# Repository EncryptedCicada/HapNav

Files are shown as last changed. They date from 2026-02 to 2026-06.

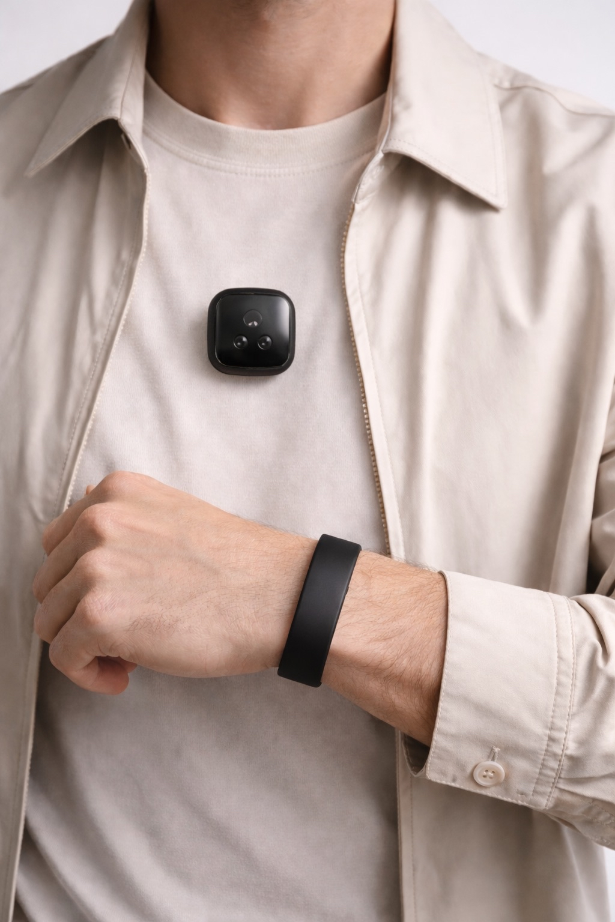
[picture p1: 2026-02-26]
Docs/Figures/Assets/HapNav_Components_Showcase-Mockup.png

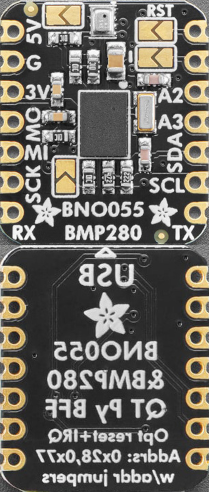
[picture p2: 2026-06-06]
Visualizer/assets/bno055+bmp280-atlas.png

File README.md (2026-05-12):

# HapNav — Haptic Navigation System for the Visually Impaired

⚠️ **This is NOT a pure software project.** HapNav requires physical hardware to build and run. You cannot simulate the full system in software alone. See the [Hardware Requirements](#hardware-requirements) section before cloning.

---

## Table of Contents

- [Overview](#overview)  
- [System Architecture](#system-architecture)  
- [Repository Structure](#repository-structure)  
- [Hardware Requirements](#hardware-requirements)  
- [Software Dependencies](#software-dependencies)  
- [Getting Started](#getting-started)  
- [Submodules](#submodules)  
- [Open Issues & Roadmap](#open-issues--roadmap)  
- [Contributing](#contributing)  
- [License](#license)

---

## Overview

HapNav is a wearable haptic navigation aid designed for visually impaired adults. The device consists of two physical components:

- A **chest-mounted pin** equipped with a Time-of-Flight (ToF) sensor array that detects obstacles in the user's path.  
- A **wrist-worn band** containing haptic actuators that translate proximity data into directional vibration feedback.

When the ToF sensor detects an obstacle within a configurable range, the system computes its angular position and distance, then drives the appropriate haptic motor on the wrist to alert the user — all in real time, with no visual or audio dependency.

**Target users:** Visually impaired adults seeking a lightweight, non-intrusive navigation supplement to white canes or guide dogs.

---

## System Architecture

```
+-----------------------------------------------+
|               Chest Unit (Pin)                |
|                                               |
|  VL53L5CX (ToF Array)                         |
|      |  8x8 depth map @ configurable rate     |
|      v                                        |
|  STM32 MCU (Zephyr RTOS)                      |
|      |  Sensor fusion: ToF + IMU + Mag        |
|      |  (LSM6DSO accel/gyro + LIS2MDL mag)    |
|      |                                        |
|      |  BLE / UART                            |
|      v                                        |
+------+----------------------------------------+
       |
       v
+-----------------------------------------------+
|               Wrist Unit (Band)               |
|                                               |
|  Haptic Driver(s)                             |
|      +-- Motor selection based on             |
|      |   obstacle angle                       |
|      +-- Intensity based on distance          |
+------+----------------------------------------+
       |
       v  (optional, for development & demo)
+-----------------------------------------------+
|        Visualizer (Host PC / Python)          |
|  Real-time ToF depth map + IMU data plot      |
+-----------------------------------------------+
```

### Data Flow

1. The VL53L5CX ToF sensor captures an 8×8 depth matrix at configurable intervals.  
2. The LSM6DSO IMU provides accelerometer and gyroscope readings for orientation correction.  
3. The LIS2MDL magnetometer provides heading data to compensate for body rotation.  
4. Sensor fusion logic on the STM32 (running Zephyr RTOS) maps the obstacle's angular position to a specific haptic driver.  
5. The haptic driver intensity is modulated based on the obstacle's proximity — closer obstacles produce stronger vibrations.  
6. Optionally, raw sensor data is streamed to the host PC for visualization and debugging via the Python Visualizer.

---

## Repository Structure

HapNav/

```
HapNav/
├── Docs/                        # Learning materials, algorithm explanations,
│                                # and component specifications
├── Reference_CodeBase/          # Simple examples to use those sensors
├── Visualizer/                  # Python-based visualization tool for
│                                # demonstrating how the ToF sensor and IMU work
├── ZephyrProject/               # Firmware for both the chest pin and the wrist band
│   ├── Drivers/                 # Git submodules for sensor drivers
│   │   ├── stm32-vl53l5cx/      # VL53L5CX ToF sensor driver (submodule)
│   │   ├── lis2mdl-pid/         # LIS2MDL magnetometer driver (submodule)
│   │   └── lsm6dso-pid/         # LSM6DSO IMU driver (submodule)
│   ├── Firmware/
│   │   ├── modules/
│   │   │   └── da7280-haptic/   # Haptic driver for Zephyr RTOS
│   │   ├── pin/                 # Chest pin firmware (ToF sensing + sensor fusion)
│   │   └── wristband/           # Wrist band firmware (haptic actuation)
│   ├── CMakeLists.txt           # Zephyr CMake build entry
│   └── prj.conf                 # Zephyr project configuration (Kconfig)
├── .gitmodules                  # Submodule definitions
└── README.md
```

### Directory Details

**`Docs/`** Contains all reference and learning materials accumulated during development — including algorithm explanations (e.g., obstacle angle computation, haptic mapping logic), component datasheets, and hardware specifications for the VL53L5CX, LSM6DSO, and LIS2MDL sensors.

**`Visualizer/`** A Python-based host tool used to demonstrate how the ToF sensor and IMU work in practice. It connects to the MCU over UART and renders the ToF depth map and IMU readings in real time. Primarily used for presentations and audience demonstrations, not required for device operation.

**`ZephyrProject/`** The core firmware of the system, split into two subdirectories targeting each physical device:

- **`pin/`** — Firmware for the chest pin. Handles ToF sensor initialization, IMU and magnetometer data acquisition, sensor fusion, and streaming processed obstacle data to the wrist band.  
- **`wristband/`** — Firmware for the wrist band. Receives obstacle data from the chest pin and drives the haptic actuators accordingly.

Both targets are written in C and built on top of Zephyr RTOS. Sensor drivers are pulled in as Git submodules under `Drivers/`.

---

## Hardware Requirements

### Required Components

| Component | Part Number | Role |
| :---- | :---- | :---- |
| MCU Board | STM32-based (e.g., NUCLEO or custom) | Main processor |
| ToF Sensor | VL53L5CX (STMicroelectronics) | Obstacle detection (8×8 depth array) |
| IMU | LSM6DSO (STMicroelectronics) | Accelerometer \+ Gyroscope |
| Magnetometer | LIS2MDL (STMicroelectronics) | Heading / orientation |
| Haptic Drivers | ERM or LRA motor drivers | Wrist vibration feedback |
| Wrist Band PCB | Custom | Houses haptic actuators |
| Chest Mount | Custom enclosure / 3D print | Houses ToF sensor \+ MCU |

### Wiring Notes

- The VL53L5CX communicates over **I2C** (address configurable via XSHUT pin).  
- The LSM6DSO and LIS2MDL also use **I2C** (or SPI for LSM6DSO depending on board config).  
- Haptic drivers are controlled via **GPIO PWM** or **I2C** depending on the driver IC chosen.  
- Refer to `Docs/` for schematics and pin assignment details.

---

## Software Dependencies

### Firmware (ZephyrProject)

| Dependency | Notes |
| :---- | :---- |
| [Zephyr RTOS](https://zephyrproject.org/) ≥ 3.x | Build system and RTOS |
| CMake ≥ 3.20 | Build toolchain |
| West (latest) | Zephyr meta-tool for workspace management |
| ARM GCC Toolchain (`zephyr-sdk`) | Cross-compiler for STM32 targets |

### Visualizer (Python)

| Dependency | Notes |
| :---- | :---- |
| Python 3.8+ | Runtime |
| `pyserial` | UART communication with MCU |
| `numpy` | Sensor data processing |
| `matplotlib` | Real-time depth map / sensor plotting |

Install Python dependencies:

pip install pyserial numpy matplotlib

---

## Getting Started

### 1\. Clone the Repository (with Submodules)

```git clone \--recurse-submodules https://github.com/EncryptedCicada/HapNav.git ```

```cd HapNav```

If you already cloned without submodules:

```git submodule update \--init \--recursive```

### 2\. Set Up the Zephyr Environment

Follow the [Zephyr Getting Started Guide](https://docs.zephyrproject.org/latest/develop/getting_started/index.html) to install West and the Zephyr SDK. Then initialize the workspace:

```west init \-l ZephyrProject```

```west update```

### 3\. Build the Firmware

Build the chest pin firmware:

```cd ZephyrProject/pin```

```west build \-b \<your\_board\> .```

Build the wrist band firmware:

```cd ZephyrProject/wristband```

```west build \-b \<your\_board\> .```

Replace `<your_board>` with your specific STM32 board identifier (e.g., `nucleo_f401re`). Board overlay files in `boards/` may need to be configured for your exact hardware setup.

### 4\. Flash to the MCU

```west flash```

Flash each firmware to its respective MCU. Ensure your board is connected via USB/SWD and the appropriate debug probe is configured in your West environment.

### 5\. Run the Visualizer (Optional)

```cd Visualizer```

```python main.py \--port /dev/ttyUSB0 \--baud 115200```

Adjust `--port` to match your system's serial port. The Visualizer renders the live ToF depth map and IMU data, useful for both development debugging and demonstrating sensor behavior to an audience.

---

## Submodules

HapNav uses three forked STMicroelectronics sensor driver libraries as Git submodules, all located under `ZephyrProject/Drivers/`:

| Submodule | Path | Description |
| :---- | :---- | :---- |
| [stm32-vl53l5cx](https://github.com/EncryptedCicada/stm32-vl53l5cx) | `ZephyrProject/Drivers/stm32-vl53l5cx` | VL53L5CX 8×8 ToF ranging sensor driver, ported for Zephyr |
| [lis2mdl-pid](https://github.com/EncryptedCicada/lis2mdl-pid) | `ZephyrProject/Drivers/lis2mdl-pid` | LIS2MDL magnetometer platform-independent driver |
| [lsm6dso-pid](https://github.com/EncryptedCicada/lsm6dso-pid) | `ZephyrProject/Drivers/lsm6dso-pid` | LSM6DSO IMU (accel \+ gyro) platform-independent driver |

All three are maintained as separate forks to allow Zephyr-specific adaptations without diverging from upstream STMicroelectronics releases.

---

## Contributing

Contributions are welcome, but please note the hardware dependency — testing any firmware changes requires the physical device. If you are contributing to the Visualizer only, a serial data replay file (if available in `Docs/`) can be used for offline testing.

1. Fork the repository  
2. Create a feature branch: `git checkout -b feature/your-feature`  
3. Commit your changes: `git commit -m "Add your feature"`  
4. Push to your fork and open a Pull Request

Please open an issue first for any significant changes to discuss the approach before implementation.

---

## License

This project does not currently specify a license. Please contact the repository owner before using, reproducing, or distributing any part of this codebase.

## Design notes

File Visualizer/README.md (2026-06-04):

# HapNav pin live visualizer

Real-time 3D viewer for the HapNav chest pin's sensor stack — three muxed
ToFs and a BNO055 IMU — rendered through [viser](https://viser.studio/).

The viewer connects to the pin's USB-Serial-JTAG console, parses the
firmware's per-sample `PIN { … }` JSON trace, and shows:

- **Front VL53L5CX (8×8 grid)** — point cloud + 64 zone rays (with optional
  clip-to-measurement and least-squares / RANSAC plane fitting). Mount: pin
  face, 8° downtilt.
- **Head VL53L1X (single zone)** — one ray and one hit point. Mount: top of
  pin face, +20° uptilt.
- **Down VL53L1X (single zone)** — one ray and one hit point. Mount: bottom
  of pin face, 45° downtilt.
- **BNO055** — every frame's quaternion rotates the entire `/pin` frame,
  so all three ToFs rotate together with the physical pin.
- **Obstacle overlay** — per-bin urgency (`L CL CR R`), nearest range, and
  decoded flag bits (`STATIONARY`, `SENSOR_BLOCKED`, `MOSTLY_INVALID`,
  `YAW_SLEWING`, `DROPOFF`, `HEAD_OBSTACLE`).

All three ToFs share the `vl53l5cx-atlas.png` texture as a placeholder
until proper VL53L1X breakout assets land — sensor kind (`GRID_8X8` vs
`SINGLE_ZONE`) drives the actual rendering, not the texture.

## Install

```bash
pip install -r viewer/requirements.txt
```

## Run

```bash
python -m viewer --port /dev/ttyACM1
```

Open <http://localhost:8080> in your browser.

**Options:**

| Flag | Default | Purpose |
|---|---|---|
| `--port`, `-p` | `/dev/ttyACM1` | Serial device for the pin's USB-Serial-JTAG |
| `--baud`, `-b` | `115200` | Baud rate |
| `--host` | `0.0.0.0` | Viser bind address |
| `--viser-port` | `8080` | Viser server port |
| `--debug`, `-d` | off | Verbose logging |

The pin's USB-Serial-JTAG typically enumerates as `/dev/ttyACMn` on Linux
(the previous Adafruit ESP32 viewer defaulted to `/dev/cu.usbserial-0001`
on macOS — adjust for your setup).

## Serial protocol the viewer expects

The pin firmware emits one line per sample (~83 Hz at 50 ms loop), prefixed
with `PIN `:

```
PIN {"ts":4763,
     "a":[ax,ay,az],          # body-frame accel (g)        — informational
     "g":[gx,gy,gz],           # body-frame gyro (rad/s)      — informational
     "q":[w,x,y,z],            # body→world quaternion (BNO055 NDOF, already remapped)
     "head":mm_or_-1,          # head VL53L1X slant range
     "down":mm_or_-1,          # down VL53L1X slant range
     "obs":{"urg":[u0,u1,u2,u3], "near":mm_or_-1, "flags":"0xNN"},
     "d":[..64..],             # front grid distances (mm) — only every ~20th sample
     "st":[..64..]             # front grid statuses     — only every ~20th sample
    }
```

The `d`/`st` grid is emitted at a fraction of the sample rate (firmware's
`dump_grid` divisor) to keep the trace stream compact; the viewer caches
the last-good grid and re-renders it between updates.

## Sensor specs

**Front VL53L5CX** ([datasheet](https://www.st.com/resource/en/datasheet/vl53l5cx.pdf)):

- FoV 65° diagonal (≈ 46° per axis, ±22.3°)
- 8×8 zones → 5.575° angular resolution per zone
- Reports perpendicular (z-axis) distance, not radial — chip does the
  conversion internally
- Range gate the viewer enforces: 50–2000 mm (matches firmware bench mode)

**Head / Down VL53L1X** (single-zone, narrow FoV ~15–27° configurable):

- Range gate the viewer enforces: 40–4000 mm
- Rendered as one ray along the sensor optical axis with a single hit
  point at the measured slant range

## Pin body / world frame conventions

The viewer uses the same convention as the firmware (`obstacle.c`):

- **Pin body frame:** +X right, +Y back, +Z up. So "forward" is **-Y**.
- **World frame:** axis-aligned with pin body in its rest pose. The BNO055
  axis remap is done in the firmware (`CONFIG=0x18`, `SIGN=0x01`), so the
  quaternion the viewer receives is already body→world — no further
  rotation correction is applied.

The pin assembly is anchored at `PIN_WORLD_POSITION` (default `(0, 0, 0.17)`,
matching the ~17 cm bench-mode mount height); tune in `viewer/config.py`.

## Mount tilt angles (configurable per ToF)

| ToF | Position on pin | Optical axis tilt |
|---|---|---|
| Front VL53L5CX | face, middle | 8° below horizontal |
| Head VL53L1X | face, top | 20° above horizontal |
| Down VL53L1X | face, bottom | 45° below horizontal |

Each ToF's mount quaternion is computed from a `R_x(90° + tilt)` rotation
in `config.py`'s `_x_axis_quat_deg()` helper — positive tilt = downward,
negative = upward.

## License

MIT

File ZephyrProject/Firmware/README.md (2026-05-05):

# HapNav Firmware

Two Zephyr applications that share a small library tree.

```
Firmware/
├── lib/ble/         shared GATT UUIDs and packet structs (header-only)
├── lib/sensors/     Zephyr glue around STMicro lsm6dso/lis2mdl drivers
├── pin/             XIAO ESP32-S3 chest pin (BLE central + sensors)
└── wristband/       XIAO nRF52840 haptic wristband (BLE peripheral)
```

The vendor STMicro `*_reg.{c,h}` files live outside this tree at
`Implementation_CodeBase/Drivers/{lsm6dso,lis2mdl}-pid/` and are pulled in
by `lib/sensors/CMakeLists.txt`.

## Build

Enter the toolchain shell first:

```zsh
nix develop ~/nixos-dotfiles#zephyr
```

### Pin (ESP32-S3)

```zsh
cd Implementation_CodeBase/Firmware/pin
west build -p always -b xiao_esp32s3 .
west flash
```

### Wristband (nRF52840)

```zsh
cd Implementation_CodeBase/Firmware/wristband
west build -p always -b xiao_ble .
west flash
```

## Runtime behaviour

After both boards are flashed:

1. Wristband boots, advertises as `HapNav-Wrist`.
2. Pin boots, scans, finds the wristband by service UUID, connects.
3. Pin discovers the two characteristics (Blink Rate, IMU Data) and caches handles.
4. Pin reads LSM6DSO + LIS2MDL at 20 Hz and streams 22-byte samples.
5. Wristband logs each sample to its serial console (a/g/m in engineering units).
6. Every 5 s the pin also bumps the wristband's blink rate (1 → 2 → … → 5 → 1).

## I2C addresses on the pin

| Sensor | Addr | Notes |
|---|---|---|
| LSM6DSO  | 0x6B | Sparkfun Qwiic default (SA0=1)  |
| LIS2MDL  | 0x1E | Fixed |

If your LSM6DSO is at 0x6A instead, change `LSM6DSO_I2C_ADDR` in
`pin/src/sensors.c`.

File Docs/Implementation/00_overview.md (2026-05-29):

# HapNav — System Overview

HapNav is a wearable proximity-cueing system for blind / low-vision users. A
chest-mounted "pin" senses the environment and a wristband converts that
data into directional haptic feedback. The two units talk over BLE.

```
┌────────────────────────────┐    BLE GATT    ┌──────────────────────┐
│  CHEST PIN                 │ Write-No-Resp  │  WRISTBAND           │
│  XIAO ESP32-S3             │ ─────────────▶ │  XIAO nRF52840       │
│                            │  219-byte frame│                      │
│  • LSM6DSO IMU             │     @10 Hz     │  • PCA9546A I2C mux  │
│  • LIS2MDL mag             │                │  • 4× DA7280 + LRA   │
│  • VL53L5CX 8×8 ToF        │                │  • TPS62827 buck on  │
│      (45°-rolled, −8° tilt)│                │    BQ25185 power-path│
│  • VL53L1X head ToF        │                │  • Drive policy 20 Hz│
│      (+20° world tilt)     │                │  • Selftest harness  │
│  • Madgwick AHRS           │                │                      │
│  • Obstacle + drop-off +   │                │                      │
│    head-clearance pipeline │                │                      │
└────────────────────────────┘                └──────────────────────┘
```

## Documentation map

| File | Subsystem |
|---|---|
| [00_system_overview.yaml](00_system_overview.yaml) | Whole-system summary (machine-readable) |
| [01_chest_pin.md](01_chest_pin.md) | Pin firmware: sensors + main loop |
| [02_wristband.md](02_wristband.md) | Wristband firmware: bring-up + threading |
| [02_wristband.yaml](02_wristband.yaml) | Wristband + selftest detail (machine-readable) |
| [03_ble_protocol.md](03_ble_protocol.md) | GATT service, frame layout, MTU |
| [04_sensor_fusion.md](04_sensor_fusion.md) | Madgwick AHRS configuration |
| [05_obstacle_detection.md](05_obstacle_detection.md) | ToF → urgency pipeline |
| [06_dropoff_detection.md](06_dropoff_detection.md) | Negative-space cliff detection |
| [07_haptic_policy.md](07_haptic_policy.md) | Wristband: urgency → LRA drive |
| [08_power_and_assembly.md](08_power_and_assembly.md) | Wristband hardware: BQ25185 → buck → mux → drivers |
| [09_head_clearance.md](09_head_clearance.md) | VL53L1X head sensor + future down-facing height calibration |
| [10_pin_power_and_assembly.md](10_pin_power_and_assembly.md) | Pin hardware: BQ25185 → 5 V boost + 3.3 V buck → I²C sensors |

## Geometry

| Quantity | Value |
|---|---|
| User height (assumed) | 175 cm |
| Sensor mount height | 1.35 m |
| Sensor downtilt | 8° |
| ToF FoV (per axis) | 44.5° |
| ToF grid | 8 × 8 (64 zones) |
| Operating range | 0.3 – 3.0 m |
| Walking-speed prior | 0.7 m/s |

## Coordinate frames

- **Sensor frame:** `+X` right, `+Y` up, `+Z` forward (optical axis)
- **Body frame:** `+X` right, `+Y` back, `+Z` up (`-Y` is user forward)
- **World frame:** Gravity-aligned, `Z` = up

## Toolchain

- Zephyr 4.4.99, west / CMake
- Pin: `xtensa-espressif_esp32s3_zephyr-elf`
- Wristband: `arm-zephyr-eabi`
- Provided via `nix develop ~/nixos-dotfiles#zephyr` (sets `ZEPHYR_BASE`,
  provides `west`)

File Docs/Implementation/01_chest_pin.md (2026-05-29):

# Chest Pin

Seeed XIAO ESP32-S3. Hosts the sensors, runs fusion + obstacle detection,
streams the result over BLE as the central / GATT client.

## Hardware

| Component | Bus | Address | Notes |
|---|-----|---|---|
| LSM6DSO 6-axis IMU | i2c0 | 0x6B | SparkFun Qwiic |
| LIS2MDL magnetometer | i2c0 | 0x1E | X axis mounted opposite IMU |
| VL53L5CX 8×8 ToF array | i2c0 | **0x29 → 0x2A at boot** | rolled 45° about optical axis |
| VL53L1X head ToF | i2c0 | 0x29 (after VL53L5CX moves) | mounted at +20° world tilt |
| VL53L1X height ToF | i2c0 | _planned_ | for live mount-height calibration; see [09_head_clearance.md](09_head_clearance.md) |

All on `i2c0`, remapped from the board-default D4/D5 to **D2 = SDA /
GPIO0_3** and **D3 = SCL / GPIO0_4** in the overlay's pinctrl block
(the original D4/D5 pads were dead on the current prototype). 400 kHz.
Both ToF sensors default to I²C address `0x29`; the firmware uses the
VL53L1X's `XSHUT` pin (**D7 = `&gpio1 12`**) to keep it offline while
the VL53L5CX is moved to `0x2A`, then releases `XSHUT` so the in-tree
Zephyr `st,vl53l1x` driver can probe at `0x29` unobstructed. See
[09_head_clearance.md](09_head_clearance.md) for the full dance.

## Firmware layout

```
Firmware/pin/
├── prj.conf                        # CONFIG_VL53L1X, CONFIG_SENSOR, …
├── boards/xiao_esp32s3.overlay     # i2c0 + tof_head node + xshut alias
├── CMakeLists.txt
└── src/
    ├── main.c       # 10 Hz sample loop
    ├── sensors.c/h  # init + sample → hapnav_frame
    └── ble.c/h      # central role; finds wristband, writes frame
```

Shared sensor glue lives at `Firmware/lib/sensors/` (Zephyr wrappers
around the STMicro platform-independent `*_reg.c` drivers + Madgwick +
the obstacle / drop-off modules).

## Sample loop

1. `hapnav_lsm6dso_read_raw()` → accel + gyro int16
2. `hapnav_lis2mdl_read_raw()` → mag int16 (X negated)
3. `madgwick_update()` with engineering-unit conversions baked in
4. `hapnav_vl53l5cx_poll()` — non-blocking; latches an 8×8 frame when ready
5. `sensor_sample_fetch()` + `sensor_channel_get()` on the VL53L1X — head
   distance in mm, or −1 when unreliable / out of range
6. `hapnav_obstacle_step()` → fills `hapnav_obstacles` block. Applies the
   45° optical-axis roll + 8° downtilt to the VL53L5CX rays, classifies
   floor/ceil/obstacle in world frame, computes per-bin urgency, runs
   drop-off + head-clearance checks
7. BLE write of the full 219-byte frame to the wristband

Period is `SAMPLE_PERIOD_MS = 100` (10 Hz) — fast enough for walking-speed
proximity, slow enough that radio + ToF stays comfortably within budget.

## Bench-demo mode

`CONFIG_HAPNAV_BENCH_MODE=y` (in `prj.conf`) rescales the obstacle /
drop-off / head-clearance constants for a desktop demo where the pin
sits 2–4 cm above the bench surface and objects move within a
10–50 cm envelope. Pair it with `CONFIG_HAPNAV_HEAD_TOF=n` to skip the
VL53L1X entirely — the VL53L5CX's ±22.3° cone is wide enough at bench
scale to cover the working volume on its own (a card waved above the
desk-mounted pin will register on the grid's top-row pixels and pulse
all four LRAs, an acceptable head-clearance proxy for the demo).

| Constant | Real-world | Bench |
|---|---|---|
| `SENSOR_HEIGHT_M` | 1.35 m | 0.04 m |
| `FLOOR_BAND_HIGH_M` | −1.20 m | −0.03 m |
| `HEAD_TOP_BAND_M` | 0.70 m | 0.10 m |
| `MIN_RANGE_MM` | 300 | 50 |
| `MAX_RANGE_MM` | 3000 | 500 |
| `CLUSTER_DELTA_MM` | 200 | 30 |
| `HEAD_PROXIMITY_MAX_MM` | 2200 | 150 |
| dropoff predicted-range cap | 3.5 m  | 0.5 m |
| stationary-detector threshold | (live) | effectively disabled |

The boot log calls out which mode the binary was built in
(`Obstacle pipeline ready [BENCH MODE] …`) so a UART capture is
unambiguous. Flip back to `=n` for the worn build.

## Build

```sh
cd ZephyrProject/Firmware/pin
west build -b xiao_esp32s3/esp32s3/procpu
west flash
```

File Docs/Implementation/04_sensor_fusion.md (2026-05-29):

# Sensor Fusion

Madgwick AHRS (MARG variant) running on the pin every 100 ms.

| Knob | Value |
|---|---|
| Algorithm | Madgwick AHRS, MARG |
| `beta` | 0.1 |
| Sample dt | 0.1 s (10 Hz, matches main loop) |

## Unit conversions before `madgwick_update`

| Sensor | LSB | Units fed in |
|---|-----|---|
| Accelerometer | `0.061 mg` per LSB | m/s² (×0.00980665) |
| Gyroscope | `70.0 mdps` per LSB | rad/s (×π/180000) |
| Magnetometer  | `1.5 mGauss` per LSB | mGauss (Madgwick only cares about ratios) |

Conversion constants are in `hapnav/ble_proto.h` (`HAPNAV_*_PER_LSB`).

## Magnetometer axis remap

The LSM6DSO and the LIS2MDL share a mounting plane but their silkscreen
axes don't line up. Empirically (and consistently with right-handed
orientation rules):

| IMU axis | Same physical direction as | Polarity |
|---|---|---|
| `IMU.X` | `Mag.Y` | same |
| `IMU.Y` | `Mag.X` | same |
| `IMU.Z` | `Mag.Z` | **opposite** |

So the pin firmware applies the mapping `(mag_imu.x, mag_imu.y,
mag_imu.z) = (mag.y, mag.x, -mag.z)` before passing the magnetic vector
to Madgwick. The X↔Y swap with a Z negation is what falls out of the two
sensors being co-planar but rotated 90° about Z and flipped about the
board plane — the right-handed coordinate convention forces the Z sign
flip once the X/Y swap is done. Consumers downstream (obstacle pipeline,
visualizer) see a single coherent right-handed sensor frame.

## What the obstacle pipeline assumes

The obstacle module receives:

- `quat_wxyz[4]` — body→world rotation
- `gyro_radps[3]` — body-frame ω
- `accel_g[3]` — body-frame specific force, gravity included

`accel_g` is used for the "stationary" detector (gravity-projected lateral
acceleration); `gyro_radps[1]` (yaw rate in body) gates the
`HAPNAV_OBS_FLAG_YAW_SLEWING` flag.

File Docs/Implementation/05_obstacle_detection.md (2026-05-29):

# Obstacle Detection

`Firmware/lib/sensors/src/obstacle.c`. Runs on the pin once per frame
(10 Hz). Inputs: 64-pixel VL53L5CX frame + Madgwick quaternion + gyro +
accel + the VL53L1X head distance. Output: the 7-byte
`hapnav_obstacles` block consumed by the wristband.

## Sensor orientation

The VL53L5CX is mounted **axis-aligned** in the chest-pin enclosure
(no optical-axis roll) and tilted **−8° downward** in world frame. The
pipeline applies the −8° tilt to the pre-computed per-pixel ray table
at init: each pixel `(r, c)` runs through `S → B mapping → R_x(+8°)`
and lands in `g_ray_B[]`.

Earlier design iterations considered a +45° physical roll on the
VL53L5CX to widen the lateral coverage from ±22.3° to ±27.5°, but the
final enclosure mounts the sensor axis-aligned. The pipeline has no
software roll to mirror.

## Pipeline

| # | Stage | Notes |
|--:|---|---|
| 1 | **Validity mask** | keep pixels whose `target_status ∈ {5, 6, 9}` and `range ∈ [300, 3000] mm`. |
| 2 | **Sensor-frame ray table** | pre-computed at init: 64 rays with the −8° downtilt baked in. |
| 3 | **World projection** | rotate every ray B→W using the current quaternion. |
| 4 | **Height classification** | floor: `world Z < −1.20 m`; ceiling: `world Z > +0.40 m` (head + 5 cm); else **candidate**. |
| 5 | **Per-bin nearest cluster** | 4 lateral bins, each 2 columns wide: `c=0,1 → LEFT`, `c=2,3 → CL`, `c=4,5 → CR`, `c=6,7 → RIGHT`. Δd threshold 200 mm, min cluster size 2 px. |
| 6 | **Closing rate** | frame-to-frame Δrange per azimuth bin; suspended while yaw is slewing (correlation breaks down). |
| 7 | **Urgency score** | `urgency = max(proximity_score, ttc_score)`, gated by motion flags. |
| 8 | **Drop-off** | bottom-row pixels feed the world-frame floor-strike check. See [06_dropoff_detection.md](06_dropoff_detection.md). |
| 9 | **Head clearance** | VL53L1X slant range ≤ 2.2 m → `HEAD_OBSTACLE`. Suppressed during yaw-slew. See [09_head_clearance.md](09_head_clearance.md). |

## Azimuth bins

```
   azimuth → −22.3° ───── −11.1° ───── 0° ───── +11.1° ───── +22.3°
              LEFT      CENTER-LEFT  │   CENTER-RIGHT      RIGHT
              c=0,1      c=2,3      │    c=4,5            c=6,7
```

Each bin is two columns wide (≈ 11.1° lateral coverage per bin). The
4-bin output drives the four LRAs on the wristband 1:1.

## Flags emitted

| Flag | Set when |
|---|---|
| `STATIONARY` | gyro magnitude + lateral accel below threshold for N frames |
| `SENSOR_BLOCKED` | majority of pixels near-field invalid (clothing, hand, etc.) |
| `MOSTLY_INVALID` | majority of pixels out-of-range (open space) |
| `YAW_SLEWING` | body-yaw rate exceeds threshold — closing-rate suspended |
| `DROPOFF` | drop-off detector trips — see [06_dropoff_detection.md](06_dropoff_detection.md) |
| `HEAD_OBSTACLE`  | VL53L1X reads ≤ 2.2 m and yaw is steady — see [09_head_clearance.md](09_head_clearance.md) |

## Tuning constants live in code

The thresholds above (200 mm, 1.20 m, 0.40 m, 2.2 m, etc.) are in
`obstacle.c`, `dropoff.c`, and `sensors.c` on the pin side. They are
intentionally *not* exposed via Kconfig because they're tied to the
sensor downtilt and mount height, which are fixed by the chest-pin
enclosure geometry. If the geometry changes, walk through
[`00_system_overview.yaml > geometry_and_physics`](00_system_overview.yaml)
and update the thresholds together.

Exception: `CONFIG_HAPNAV_BENCH_MODE` swaps the whole set of
distance-tied constants for a bench-scale equivalent so the pipeline
can be exercised on a desk. See [`01_chest_pin.md > Bench-demo
mode`](01_chest_pin.md) for the full re-scaling table.

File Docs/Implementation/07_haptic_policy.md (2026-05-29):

# Haptic Drive Policy

`Firmware/lib/haptics/src/haptics.c`. Translates each incoming
`hapnav_obstacles` block into per-LRA pulses — short, hard hits whose
*rate* encodes urgency. Bench testing on the SparkFun haptic stack
showed continuous graded-amplitude drive was hard to feel through the
wrist strap; short bangs are clearly perceptible.

## Why a separate worker, not the BLE callback

The pin's BLE arrival rate is **10 Hz**, but the pulse cycles, drop-off
square wave, fatigue decay, and watchdog mute all want a stable clock
independent of radio jitter. So:

```
BT RX  ──▶  latch (mutex)  ──▶  haptics_tick (20 Hz)  ──▶  4× LRA
```

`haptics_tick` runs on the system work-queue every 50 ms. It always
ticks, even with no recent frame — that's how the watchdog can mute.

## Stage overview

```
worker_tick():
    read latch under mutex
    if watchdog tripped: drive all 0, mark was_stale, continue
    if any override (drop-off / head / mute): drive that pattern
    else for each channel:
        target  = urgency → intensity (yaw-slew dampened, fatigue-attenuated)
        period  = target → ticks between pulses
        pulse(channel, period)
```

The pulse model means a channel is **either** firing a single tick at
`DRIVE_MAX` or sitting silent — there is no held intermediate level.
Intensity is encoded purely as **pulse rate**.

### 1. Watchdog

If `now − latch.rx_time_ms > 250 ms`, every channel goes immediately to
0 and the per-channel pulse phases reset. With the policy idle thereafter
the wristband is silent within one tick (~50 ms).

### 2. Flag gating

Before deriving pulse rates from `urgency[]`:

| Flag | Action |
|---|---|
| `STATIONARY` ∨ `SENSOR_BLOCKED` ∨ `MOSTLY_INVALID` | mute (drive 0, reset pulse phases) |
| `DROPOFF` | drop-off override (stage 3a); urgency ignored |
| `HEAD_OBSTACLE` | head-obstacle override (stage 3b); urgency ignored |
| `YAW_SLEWING` | dampen target intensity × 0.4 → longer pulse period |

Priority when multiple flags fire: **drop-off > head-obstacle > mute >
urgency-pulse**. Falling outranks bumping; bumping outranks brushing.

### 3a. Drop-off override

When `DROPOFF` is set, all four channels are driven in lock-step:
3 ticks at `DRIVE_MAX`, 3 ticks at 0 (≈ 150 ms / 150 ms square wave,
≈ 3.3 Hz). This deliberately uses a coordination pattern that the
urgency-pulse path never produces, so the user can disambiguate cliff
from wall.

### 3b. Head-obstacle override

When `HEAD_OBSTACLE` is set (and `DROPOFF` is not), only the **outer
pair** of LRAs (LEFT + RIGHT) pulse at `DRIVE_MAX`, alternating
1 tick on / 1 tick off (≈ 50 ms / 50 ms, 10 Hz). Centre channels stay
quiet. The fast bracketing pulse is perceptually distinct from the
slower all-four drop-off pattern.

### 4. Urgency intensity (target)

For each channel that's not under an override:

```
urgency < 32           → target = 0      (perceptual floor)
urgency ≥ 32           → target = DRIVE_MAX × (u − 32) / (255 − 32)
target  < 8            → target = 0      (LRA dead-band)
```

If `YAW_SLEWING` is set, `target` is multiplied by 0.4 — the gain
reduction translates downstream into a slower pulse rate, not a softer
hit.

`DRIVE_MAX` is **60 / 127** (≈ 47 %). The DA7280 in DRO mode with
acceleration enabled treats `TOP_CTL2` as 7-bit signed; the 60 cap
matches the DT `per-channel-drive-cap` and keeps four channels at
simultaneous firing inside the BQ25185 LOAD pin budget.

### 5. Fatigue (per channel)

A leaky bucket measured against actual pulse-on ticks:

```
on_ms[i] += 50  when this tick fired (cur_amp == DRIVE_MAX)
on_ms[i] −= 50  when this tick was silent (clamped ≥ 0, ≤ 5000)
duty       = on_ms[i] / 5000
```

When `duty > 0.7`, `target` tapers linearly down to **0.4×** at
`duty = 1.0`. Because the pulse rate is derived from `target`, this
shows up as **fewer pulses**, not weaker pulses. A channel pulsing
flat-out (6.7 Hz) drops to ~ 1.3 Hz once the bucket fills, which
re-introduces perceptual novelty between hits.

### 6. Pulse period

```
period_ticks =  PULSE_PERIOD_SLOW
              − (target − DRIVE_MIN_PERCEPT) × (SLOW − FAST) / (DRIVE_MAX − DRIVE_MIN_PERCEPT)
```

`PULSE_PERIOD_FAST_TICKS = 3` (150 ms = 6.7 Hz) at full intensity.
`PULSE_PERIOD_SLOW_TICKS = 20` (1 s = 1 Hz) just above the perceptual
floor. Below the floor → period = 0 = channel muted.

### 7. Drive

For each channel whose current pulse phase rolls over the computed
period, fire one tick (50 ms) at `DRIVE_MAX`; otherwise hold 0:

```
da7280_set_amplitude(lras[ch], fire ? DRIVE_MAX : 0);
```

The four `lras[]` are device handles resolved from DT aliases
(`hapnav-lra-l/cl/cr/r`). Zephyr's in-tree `ti,tca9546a` mux driver
silently selects the right child bus before every I²C transaction, so
this layer never touches the PCA9546A directly. The DA7280's
acceleration mode + `dlg,rapid-stop-enable` handle the mechanical
attack/decay inside that 50 ms window — the chip brakes the LRA back
to 0 cleanly, which is what makes the pulses feel discrete instead of
ringing into each other.

The policy keeps a per-channel `cur_amp` so it only writes I²C when the
drive level actually changes (every tick of the gap is a no-op after
the first).

## Safety

| Concern | Mitigation |
|---|---|
| Pin reboot / link drop | watchdog mute (stage 1) |
| Stuck-on amplitude | fatigue (stage 5) slows pulse rate automatically |
| Voltage transients | DA7280 ABS / NOM = 2.5 Vrms hard programmed; `DRIVE_MAX = 60` keeps below acceleration-mode max |
| Simultaneous 4-channel pulse | per-channel cap × 4 = 240, `CONFIG_HAPTIC_DA7280_TOTAL_DRIVE_CAP = 250` backstops |
| Boot order | `main.c` calls `hapnav_haptics_init()` *before* BLE, so a stale `latch` (`valid = false`) keeps motors silent during BT advertising |

## Tuning constants

All policy knobs live as `#define`s at the top of `haptics.c`:

```
DRIVE_PERIOD_MS         50      # worker tick
WATCHDOG_MS             250
URGENCY_FLOOR           32      # below this → silent
DRIVE_MAX               60      # per-channel cap (out of 127)
DRIVE_MIN_PERCEPT       8       # target below this → 0
PULSE_ON_TICKS          1       # 50 ms hit per pulse
PULSE_PERIOD_FAST_TICKS 3       # 150 ms cycle at max urgency (6.7 Hz)
PULSE_PERIOD_SLOW_TICKS 20      # 1 s cycle just above floor (1 Hz)
YAW_SLEW_GAIN_NUM/DEN   2/5     # 40 % during head turns
DROPOFF_HALF_TICKS      3       # 3 × 50 ms = 150 ms half-period (3.3 Hz)
HEAD_HALF_TICKS         1       # 1 × 50 ms = 50 ms half-period (10 Hz)
FATIGUE_WINDOW_MS       5000
FATIGUE_HIGH_NUM/DEN    7/10    # taper above 70 % bucket fill
FATIGUE_FLOOR_NUM/DEN   2/5     # taper bottoms at 40 % of original intensity
```

Anything user-perceivable should be tuned by physical trial on a real
wearer; reading these numbers off paper isn't enough.

## Bench testing without a pin

`hapnav_haptics_inject(struct hapnav_obstacles *)` is a public API used
in place of `hapnav_haptics_consume_frame()`. The selftest harness
(`CONFIG_HAPNAV_SELFTEST=y`) uses it during the simulated-obstacle
phase. Note: with the pulse model, `log_cur_amps()` snapshots the
instantaneous drive level (0 or `DRIVE_MAX`), not a held average — read
it as *"did this channel just fire?"* rather than *"how loud is this
channel?"*.

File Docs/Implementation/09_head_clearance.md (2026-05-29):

# Head Clearance & Future Height Calibration

The chest pin now carries a single-zone **VL53L1X** alongside the
**VL53L5CX**. The two sensors share `i2c0`, divide the pin's field of view
between them, and rely on an `XSHUT`-driven address shuffle at boot
because they both default to 7-bit `0x29`.

```
                                    ┌──────────────┐
        head-clearance cone         │              │
        (VL53L1X, +20° tilt,        │  user        │
        ≈ 27° FoV)                  │              │
                ╲╲╲                 │              │
                  ╲╲╲╲              │  ◄─ obstacle │
                    ╲╲╲╲            │              │
   pin   ────────────────────►       1.75 m ▲
   1.35 m    ───────────────────►            │
   above     ╱ ╱ ╱ ╱ ╱ ╱  forward            │
   floor   ╱ ╱ ╱ ╱ ╱        VL53L5CX         │
         ╱ ╱ ╱ ╱   (axis-aligned grid,        │
       ╱ ╱ ╱ ╱     −8° downtilt)      floor ▼
     ╱ ╱ ╱
   floor
```

## VL53L1X (head) — geometry

| Parameter | Value | Notes |
|---|---|---|
| Mount height | 1.35 m | shared with VL53L5CX |
| Optical-axis tilt | **+20° above world horizontal** | nose-up relative to VL53L5CX |
| Tilt relative to VL53L5CX face | **+28°** | the chest pin face is at −8° downtilt |
| Cone FoV | ≈ 27° full-cone | sensor default; no ROI shrink |
| Useful range | 0.3 – 4.0 m | datasheet typical |
| Sample rate | 10 Hz | locks with VL53L5CX cadence |
| Proximity flag threshold | 2.2 m slant range | tuned for the envelope below |

### Detection envelope

Cone vertical span at distance L: `L × (tan(33.5°) − tan(6.5°)) ≈ L × 0.55`.

| Forward distance | Cone bottom (world Z) | Cone top (world Z) | Catches |
|---|---|---|---|
| 1.0 m | 1.46 m | 2.01 m | forehead, jaw, chin-level shelf edges |
| 1.5 m | 1.52 m | 2.34 m | forehead → above doorframes |
| 2.0 m | 1.58 m | 2.67 m | low-hanging signs, low branches |
| 2.5 m | 1.64 m | 3.01 m | door frames at the far edge of reaction time |

At a 0.7 m/s walking-speed prior the user has ≈ 2.1 s to react when an
obstacle first enters the cone at 1.5 m forward. The 2.2 m proximity
threshold is conservative — by the time we flag, the obstacle is inside
the cone and within ~1.6 m forward (allowing for some slant on the cone).

### Why this tilt, not something else

- `+15°` was the alternative. It buys extra range on far-forward
  obstacles (catches a doorframe at 3.5 m) but loses the close-in
  envelope inside ~80 cm — exactly the distance where a user has
  already started leaning into the obstacle. Trade-off rejected.
- `+25°` ducks the close envelope tighter but starts to miss
  standard 2.0 m doorframes at the 2 m forward mark, which is the
  primary failure case we're trying to prevent.

## I²C address shuffle (bring-up sequence)

Both VL53L5CX and VL53L1X power up at 7-bit `0x29`. Until a mux is
present on the pin we sequence them with the VL53L1X's `XSHUT` line:

1. **Hold `XSHUT` low** before any I²C traffic. The pin firmware does
   this in `pin_sensors_init()` via `gpio_pin_configure_dt(&head_xshut,
   GPIO_OUTPUT_INACTIVE)`. Active-high in DT means asserted-high = on;
   inactive = low = sensor in reset.
2. **Bring up the VL53L5CX** at 7-bit `0x29` (vendor ULD).
3. **Move the VL53L5CX to 7-bit `0x2A`** using the ULD's
   `vl53l5cx_set_i2c_address()`. The new address survives until the
   next power cycle.
4. **`device_init(tof_head)`** — Zephyr's in-tree VL53L1X driver is
   marked `zephyr,deferred-init` so it hasn't probed yet. The
   `device_init()` call drives `XSHUT` high, waits the chip's 1.2 ms
   boot time, and probes at the now-free `0x29`.

Addresses are not persistent on either chip. On every power cycle the
VL53L5CX boots back at `0x29`, and the shuffle repeats.

The DT alias `hapnav-tof-head` points at the VL53L1X node so the
firmware can resolve the `XSHUT` GPIO without hard-coding which `&gpioN
M` it lives on. Pin assignment is `D7 = &gpio1 12` (ESP32-S3 GPIO44 —
default UART0 RX, but the console runs over USB-Serial-JTAG so the pin
is free).

## Wristband response — `HAPNAV_OBS_FLAG_HEAD_OBSTACLE`

When the head sensor sees a target inside the proximity threshold, the
pin sets the new `(1U << 5)` flag in `hapnav_obstacles.flags`. The
wristband's haptic policy reacts:

- **Outer pair only** (LEFT + RIGHT) at full amplitude, pulsing at 10 Hz
  (50 ms on / 50 ms off). Centre channels stay quiet.
- Distinct from drop-off (all-4 at 3.3 Hz, slower) and from
  directional-obstacle drive (graded amplitude, no pulse).
- Suppressed during yaw-slew so a head turn past a sign doesn't
  spuriously trigger.
- Drop-off wins if both flags fire — falling outranks bumping.

Selftest case "head-obstacle flag" in T7 exercises the pattern with no
hardware needed (injects the flag for 700 ms).

## Future: down-facing VL53L1X for height calibration

When the second VL53L1X arrives — currently blocked on procuring an
I²C mux for the pin (or, alternatively, the same XSHUT/address dance
applied to a third chip) — it earns a fixed slot on the pin enclosure
pointing **straight down**, possibly tilted −80° to clear the user's
feet during a casual look-down.

### What it does

One-shot reading at startup (or when triggered by a "stood still for 3
seconds" detector via the IMU). The measured distance is the live
sensor mount height, which today is hard-coded as `SENSOR_HEIGHT_M =
1.35 f` in `obstacle.c` and `dropoff.c`. With per-user calibration the
floor-classification band, drop-off predicted slant range, and head
clearance envelope all retune themselves.

### Why not just use the IMU + accelerometer?

The IMU gives orientation, not absolute height above floor. Without a
direct measurement we'd have to ask the user (height in cm) and assume
where they wear the pin — both error-prone for a wearable for blind
users.

### Address-conflict options for the second VL53L1X

We have three. None is in the firmware today; this is a roadmap.

| Option | Pros | Cons |
|---|---|---|
| **TCA9548A I²C mux** on the pin | Same model as the wristband. Future-proof if a fourth sensor (e.g. flank-facing ToF) lands later. | Adds a part. |
| **XSHUT + address swap on the second VL53L1X** | No new silicon. Mirrors the current head-sensor dance. | Two `XSHUT` GPIOs on the pin (D2 already used; add D3). |
| **Defer to head-sensor's spare cycles** | No new bus mods at all — re-use the same VL53L1X by temporarily re-aiming it. | Mechanically infeasible on a fixed-mount pin. |

When the second sensor lands, the XSHUT option is what this doc
recommends; the mux is justified only when we know a third sensor is
imminent. Document the choice in this section before any code lands.

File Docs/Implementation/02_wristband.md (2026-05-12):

# Wristband

Seeed XIAO nRF52840. BLE peripheral / GATT server. Receives the pin's
frame, runs the haptic policy, drives four LRAs.

For the supply-side topology (BQ25185 charger → TPS62827 buck → mux +
drivers), see [`08_power_and_assembly.md`](08_power_and_assembly.md).

## Hardware

| Component | Bus | Address |
|---|-----|---|
| PCA9546A 4-channel I2C mux | i2c1 | 0x70 |
| 4× DA7280 haptic driver | virtual i2c per mux ch | 0x4A |
| 4× G1040003D LRA | DA7280 OUT pins | — |

All four DA7280s share the same 7-bit I2C address; the PCA9546A isolates
them. We use Zephyr's in-tree `ti,tca9546a` driver — its binding header
explicitly notes "compatible with NXP PCA9546A" — and it publishes each
mux channel as a virtual i2c bus, so each DA7280 becomes an ordinary DT
node at 0x4A on its own child bus.

The parent bus is `i2c1` on the SoC — the XIAO routes that to D4 (SDA,
P0.04) and D5 (SCL, P0.05), which is the board's Qwiic-compatible
pinout. The board common dtsi already enables `i2c1` with pinctrl; the
overlay raises the bitrate to 400 kHz, instantiates the mux at 0x70 with
`i2c-mux-idle-disconnect`, and creates four `dlg,da7280` nodes.

Channel-to-role mapping (matches `hapnav_obstacles.urgency[]` indexing
on the pin):

| Mux ch | Alias | Role | LRA position |
|---|---|---|---|
| 0 | `hapnav-lra-l`  | LEFT | outer-left |
| 1 | `hapnav-lra-cl` | CENTER-LEFT | inner-left |
| 2 | `hapnav-lra-cr` | CENTER-RIGHT  | inner-right  |
| 3 | `hapnav-lra-r`  | RIGHT | outer-right  |

The high-level policy resolves the four DT aliases into device handles
and never has to touch the mux directly.

## Firmware layout

```
Firmware/
├── modules/da7280-haptic/        # out-of-tree Zephyr module
│   ├── zephyr/module.yml
│   ├── drivers/haptic/{da7280.c, CMakeLists.txt, Kconfig}
│   ├── dts/bindings/i2c/dlg,da7280.yaml
│   └── include/zephyr/drivers/haptic/da7280.h
│
├── lib/haptics/                  # high-level policy + selftest harness
│   ├── include/hapnav/haptics.h
│   ├── src/haptics.c
│   ├── Kconfig                   # HAPNAV_HAPTICS, HAPNAV_SELFTEST
│   └── CMakeLists.txt
│
└── wristband/
    ├── prj.conf
    ├── boards/xiao_ble.overlay   # i2c1 + tca9546a@70 + 4 DA7280 nodes
    ├── CMakeLists.txt            # registers da7280-haptic via ZEPHYR_EXTRA_MODULES
    ├── Kconfig                   # sources lib/haptics/Kconfig
    └── src/
        ├── main.c                # haptics_init() then ble_init()
        └── ble.c/h               # GATT peripheral; latches obstacles, prints JSON
```

## Threading

- **BT RX context** — `frame_write()` GATT callback hands the 7-byte
  `hapnav_obstacles` block to `hapnav_haptics_consume_frame()`, which
  stores it under a mutex with a `k_uptime_get_32()` stamp. In selftest
  mode this is a no-op (the JSON debug print still runs so the link is
  observable on UART).
- **System work-queue** — `worker_tick()` runs every 50 ms (20 Hz). It
  reads the latch, applies the [drive policy](07_haptic_policy.md),
  and issues `da7280_set_amplitude()` whenever a channel's amplitude
  actually changed.
- **Selftest thread** (only when `CONFIG_HAPNAV_SELFTEST=y`) — a
  dedicated thread executes T0–T10. T0–T6 drive chips directly; the
  worker is held back until T7 so it doesn't fight the raw-chip phase.
  T7–T10 inject synthetic obstacles and rely on the worker to evolve
  rate-limit / fatigue / watchdog state.

The drive cadence is decoupled from BLE arrival, so smoothing, drop-off
pulses, and the watchdog mute all run on a stable clock even if the
radio link stutters.

## DA7280 driver

Lives at `Firmware/modules/da7280-haptic/` as a proper out-of-tree
Zephyr module: `DT_DRV_COMPAT dlg_da7280`, per-instance config from DT,
uses `i2c_dt_spec` so the in-tree mux driver transparently selects the
channel before every transaction.

Coverage:

- CHIP_REV detection, full TOP_CFG1..5 setup, V2I calibration
- DRO hot path: TOP_CTL2 single-byte amplitude write
- Auto INACTIVE↔DRO mode toggle on amp 0↔non-zero
- Global drive budget (`CONFIG_HAPTIC_DA7280_TOTAL_DRIVE_CAP`)
- IRQ workqueue (irq-gpios optional; we don't wire one)
- `CONFIG_HAPTIC_DA7280_SAFE_INIT` — defang prologue (TOP_CTL2=0,
  OP_MODE=INACTIVE) before any config, to survive host-side resets
  while the chip keeps power
- VDD ADC and CALIB_IMP readbacks for telemetry
- RTWM/ETWM and waveform-memory upload exist in the driver but the
  policy doesn't use them yet

The Linux-kernel reference at `ZephyrProject/Drivers/da7280/da7280.c`
is kept for documentation — it uses regmap, `work_struct`, threaded
IRQs, and the FF input subsystem, none of which exist on Zephyr, so we
don't try to compile it.

## Selftest

`CONFIG_HAPNAV_SELFTEST=y` swaps the BLE-driven path for an isolated
bench-test sequence. See [`02_wristband.yaml`](02_wristband.yaml)
for the full T0–T10 list; in summary:

| Phase | Tests | What it exercises |
|---|---|---|
| Raw chip | T0 probe, T1 channel walk, T2 ramp, T3 crossfade, T4 all-on stress, T5 update-rate stress, T6 dropoff square wave | DA7280 driver + mux, supply rail under load, I2C bandwidth, IRQ surveillance |
| Policy | T7 simulated obstacles, T8 fatigue taper, T9 watchdog mute, T10 idle hold | Full pipeline (latch → worker → set_amplitude) on synthetic input |

## Build

```sh
cd ZephyrProject/Firmware/wristband
west build -b xiao_ble
west flash
```

Toggle the selftest gate in `prj.conf`:

```kconfig
CONFIG_HAPNAV_SELFTEST=y    # bench validation (default for v4)
CONFIG_HAPNAV_SELFTEST=n    # normal navigation — react to BLE frames
```

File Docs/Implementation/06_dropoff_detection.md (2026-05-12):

# Drop-off Detection

`Firmware/lib/sensors/src/dropoff.c`. Geometric reasoning over the
*absence* of returns: a step down or hole in the floor shows up as
missing pixels in the bottom rows of the ToF grid where we expect floor
hits.

## Logic

For each pixel that looks at least ~11.5° below horizontal in world
frame, the module knows the world-frame ray (from the same
pre-computed table the obstacle pipeline uses) and the predicted
distance at which that ray should intersect the floor plane
`Z = −1.20 m`.

The pipeline applies a +45° optical-axis roll to the VL53L5CX rays
before this module sees them. The detector is **rotation-invariant** —
it uses each ray's world-frame Z component, not the pixel's grid
position — so the eligible "floor rays" are now the lower triangle of
the diamond (corner pixel pointing straight down, plus its neighbours).
The corner pixel strikes the floor at ~1.89 m forward instead of the
unrotated bottom-row's 2.31 m; the detection envelope is therefore
slightly closer-in but compensated by the wider lateral spread of
floor rays across the diamond's bottom half.

A pixel votes for drop-off if either:

1. it returned **no valid status** while a floor return was expected, **or**
2. its measured range exceeds **1.3×** the predicted floor range — i.e.
   the floor stepped down at least far enough to push the hit out of the
   tolerance.

If **≥ 3 pixels** in the expected-floor band vote, `HAPNAV_OBS_FLAG_DROPOFF`
is set on the frame.

## Why a square-wave on the wristband

A drop-off is qualitatively different from a wall: walls warrant
"slow down", drop-offs warrant "stop now". To make that distinction
unambiguous on the haptic side, the wristband translates the flag into a
distinctive square-wave pattern on **all four** LRAs in unison (150 ms
on / 150 ms off, ≈3.3 Hz). See
[`07_haptic_policy.md`](07_haptic_policy.md).

Pulse-on-all-four is a deliberately rare cue in normal proximity output
— normal output decorrelates across channels by direction — so the
"everything pulsing" pattern reliably reads as "stop".

## Tuning

Threshold (`≥ 3 pixels` and `1.3× ratio`) lives in `dropoff.c`. Tightening
either reduces false drop-off cues at the cost of late detection; loosening
raises false positives, which the user perceives as a phantom cliff —
much worse than a missed wall, since they will physically stop walking.

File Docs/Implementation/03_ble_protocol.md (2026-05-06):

# BLE Protocol

One custom GATT primary service, one writable characteristic. The pin
(central) connects to the wristband (peripheral) and pushes the latest
fused frame using `Write Without Response`.

Defined in `Firmware/lib/ble/include/hapnav/ble_proto.h`; this header is
the single source of truth shared by both targets.

## Service & characteristic

| | UUID base |
|-|---|
| Service | `5a9c0001-7e6f-4abc-9c12-aabbccdd1100` |
| Frame | `5a9c0004-7e6f-4abc-9c12-aabbccdd1100` |

UUIDs are derived via `HAPNAV_UUID_VAL(0x000N)`.

## MTU

```
CONFIG_BT_L2CAP_TX_MTU=247
CONFIG_BT_BUF_ACL_RX_SIZE=251
CONFIG_BT_BUF_ACL_TX_SIZE=251
```

Negotiated MTU is 247, which fits the 219-byte frame in a single ATT PDU
and leaves 4 bytes of L2CAP header inside a 251-byte ACL buffer.

## Frame layout (219 bytes, packed)

| Offset | Field | Type | Notes |
|---:|---|---|---|
| 0 | `timestamp_ms` | `uint32` | `k_uptime_get_32()` at frame assembly |
| 4 | `quat[4]` | `float32` | unit quaternion `[w, x, y, z]`, Madgwick |
|  20 | `distances_mm[64]`| `int16`  | VL53L5CX 8×8 distances |
| 148 | `target_status[64]`| `uint8` | VL53L5CX status flags |
| 212 | `obstacles.urgency[4]` | `uint8` | L, CL, CR, R (0–255) |
| 216 | `obstacles.nearest_range_mm` | `int16` | -1 if clear |
| 218 | `obstacles.flags` | `uint8` | bitfield, see below |

```
HAPNAV_OBS_FLAG_STATIONARY      (1 << 0)
HAPNAV_OBS_FLAG_SENSOR_BLOCKED  (1 << 1)
HAPNAV_OBS_FLAG_MOSTLY_INVALID  (1 << 2)
HAPNAV_OBS_FLAG_YAW_SLEWING     (1 << 3)
HAPNAV_OBS_FLAG_DROPOFF         (1 << 4)
```

## Channel mapping (azimuth bins)

| index | name | azimuth bin |
|---:|---|---|
| 0 | LEFT | [-22.3°, -11.1°] |
| 1 | CENTER-LEFT | [-11.1°, 0°  ] |
| 2 | CENTER-RIGHT  | [ 0° , +11.1°] |
| 3 | RIGHT | [+11.1°, +22.3°] |

One bin = two columns of the 8-wide ToF grid.

## What the wristband consumes

Of the 219 bytes the pin sends, the haptic policy only acts on:

- `timestamp_ms`            — for the watchdog
- `obstacles.urgency[4]`    — per-channel drive target
- `obstacles.flags`         — gating + drop-off pulse pattern

The full frame is still printed as JSON over UART for bring-up debugging
(`print_frame_json()` in `wristband/src/ble.c`).

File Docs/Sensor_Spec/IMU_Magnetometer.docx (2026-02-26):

1. Architecture layout

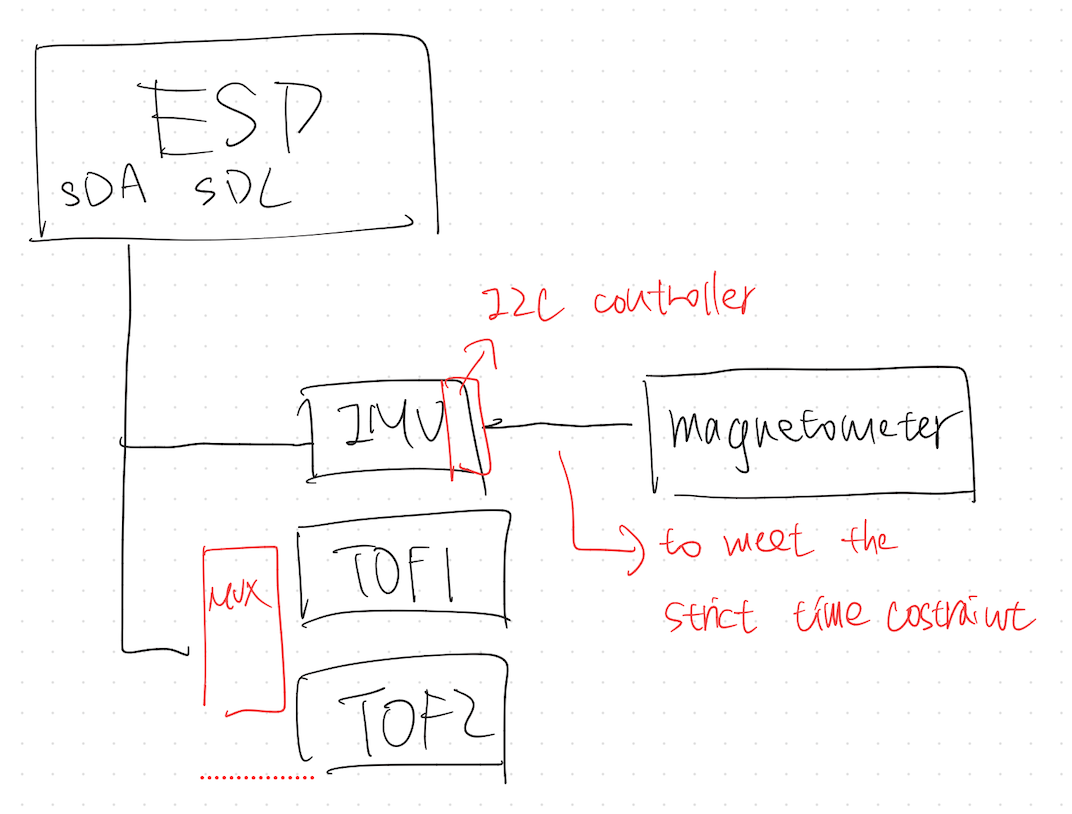
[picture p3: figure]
一張含有 文字, 筆跡, 寫生, 圖畫 的圖片 AI 產生的內容可能不正確。

2. IMU + magnetometer
  1、 IMU acts as a sensor hub(9KB FIFO) to store the data from the magnetometer
    i. Reason: save power / unified timestamp / release the loading of IMU
  2、 How to connect
    i. Sensor hub / AUX I2C
    ii. SCL / SDA of the magnetometer connect to AUX I2C of IMU
  3、 How to boot
    i. Init stage(ESP behavior)
      1. ESP init I2C (ESP & IMU)
      2. Set IMU (ODR / FIFO / interrupt)
      3. Set Sensor Hub interaction
        1、 Which external sensor (e.g., magnetometer)
        2、 Which control register
        3、 Which data register
        4、 Set frequency (same as acc / gyro)
    ii. Runtime
      1. IMU
        1、 periodically read the external sensor(e.g., megnetometer), and put it into the 9KB FIFO
      2. ESP
        1、 Wait for watermark interrupt or interrupt to read 9KB FIFO
        2、 Get the accel/gyro + mag + timestamp
  4、 Github: https://github.com/STMicroelectronics/STMems_Standard_C_drivers/tree/master/lsm6dso_STdC/examples

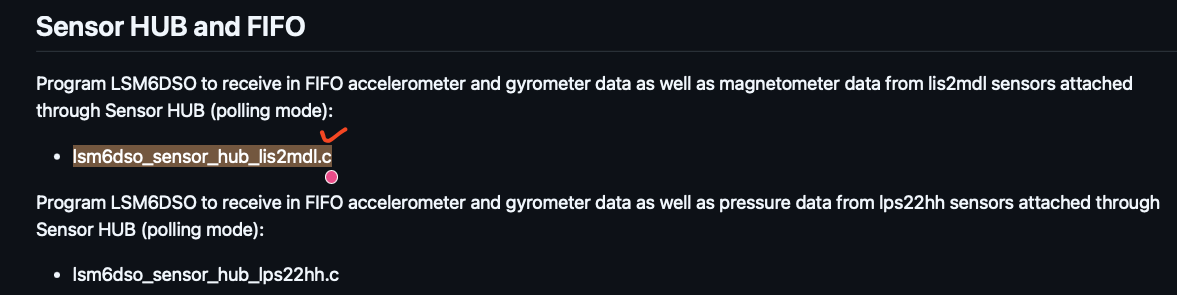
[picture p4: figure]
一張含有 文字, 螢幕擷取畫面, 字型 的圖片 AI 產生的內容可能不正確。

  5、 Note:
    i. Even though the program is only flashed into the ESP, the IMU can still read the data from the magnetometer actively.
    ii. ESP has to set the Sensor Hub in the IMU
    iii. IMU would get the data from the magnetometer, and move it to the FIFO based on the instruction given by the ESP

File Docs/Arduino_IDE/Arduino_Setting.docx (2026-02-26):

1. Board: classic esp32 instead of esp32-s

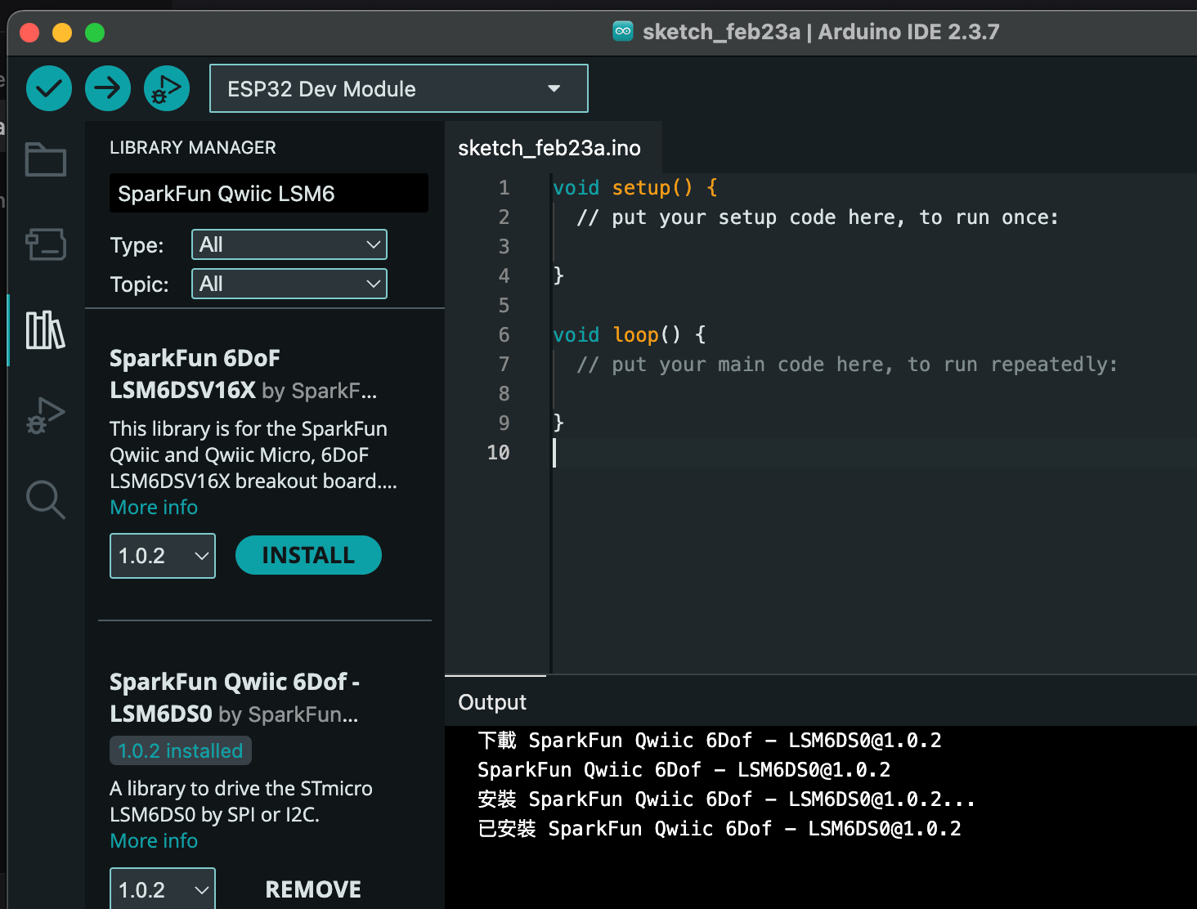
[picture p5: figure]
一張含有 文字, 螢幕擷取畫面, 軟體, 多媒體軟體 的圖片 AI 產生的內容可能不正確。

3. Rember to select port to upload the binary

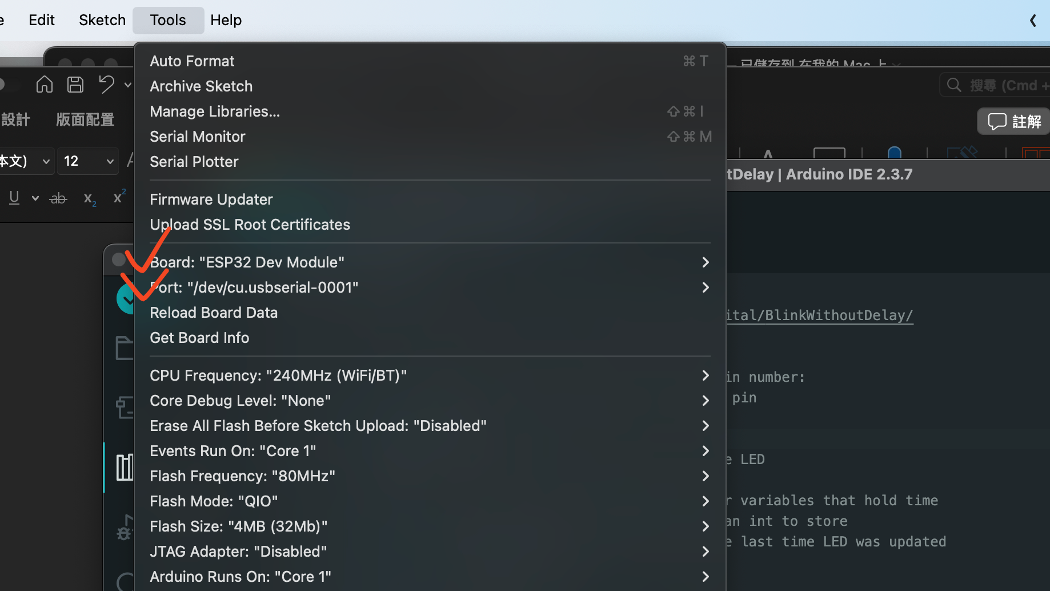
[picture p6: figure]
一張含有 文字, 軟體, 多媒體軟體, 繪圖軟體 的圖片 AI 產生的內容可能不正確。
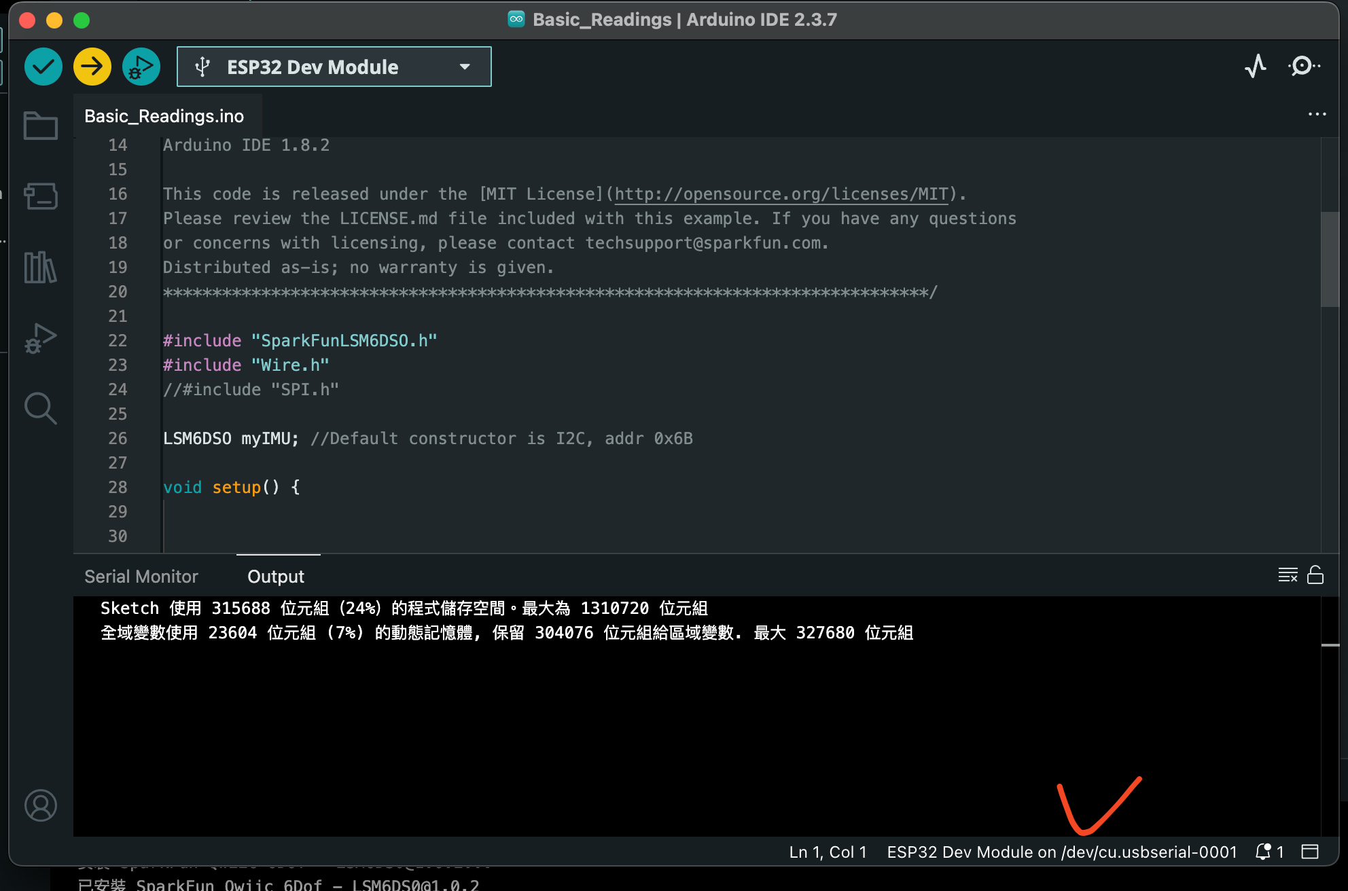
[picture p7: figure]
一張含有 文字, 螢幕擷取畫面, 軟體, 多媒體軟體 的圖片 AI 產生的內容可能不正確。

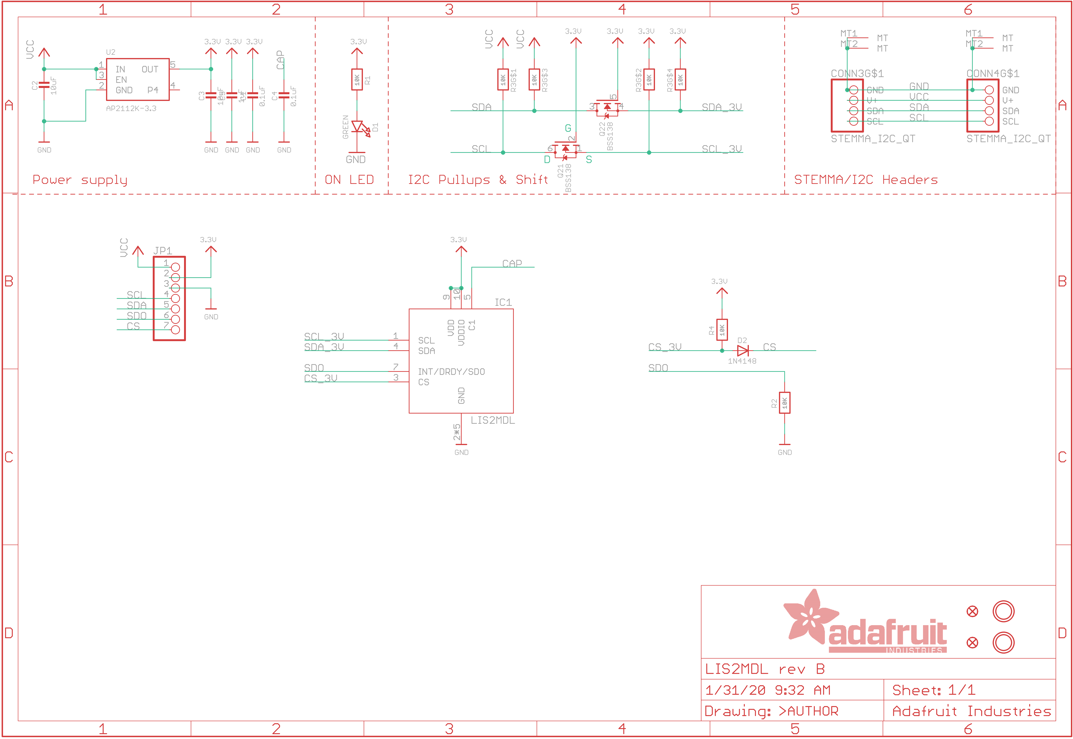
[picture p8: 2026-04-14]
Docs/Figures/Board_Schematics/Adafruit_LIS2MDL.png

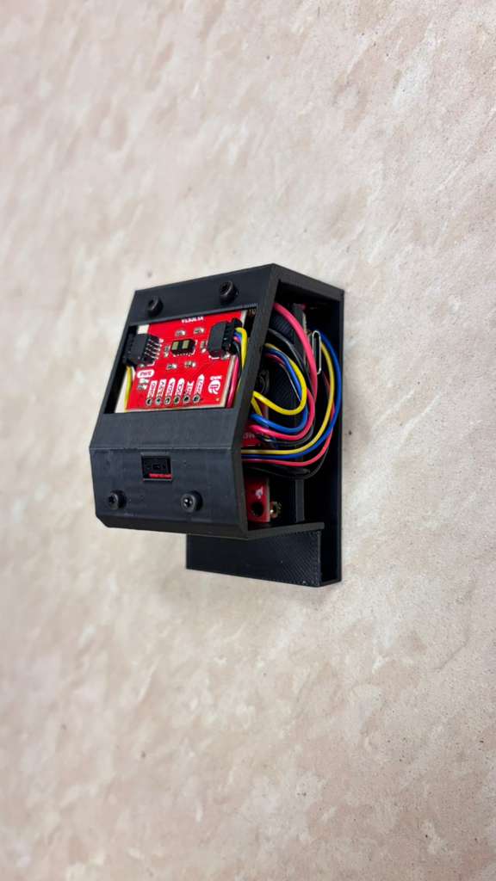
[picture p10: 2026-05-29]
Docs/Figures/Assets/Pin_Prototype.jpeg

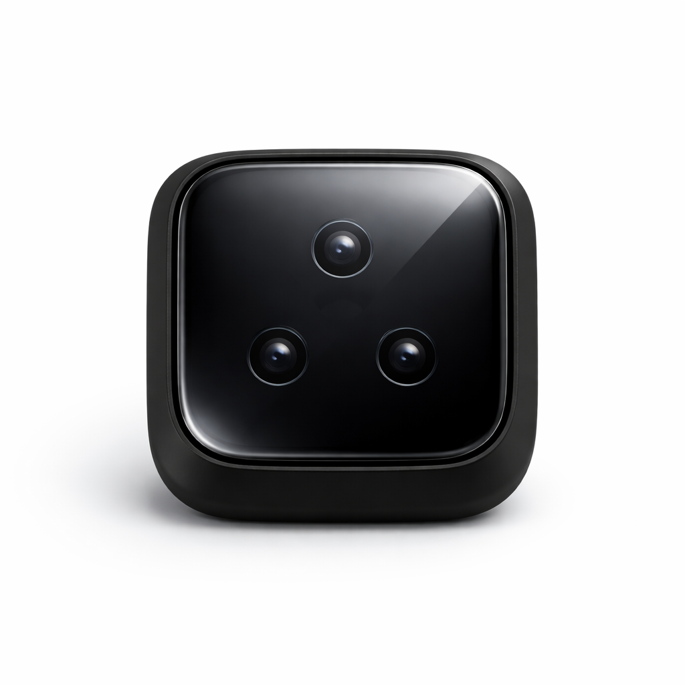
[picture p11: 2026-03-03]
Docs/Figures/Assets/HapNav_Pin-AI_Render.png

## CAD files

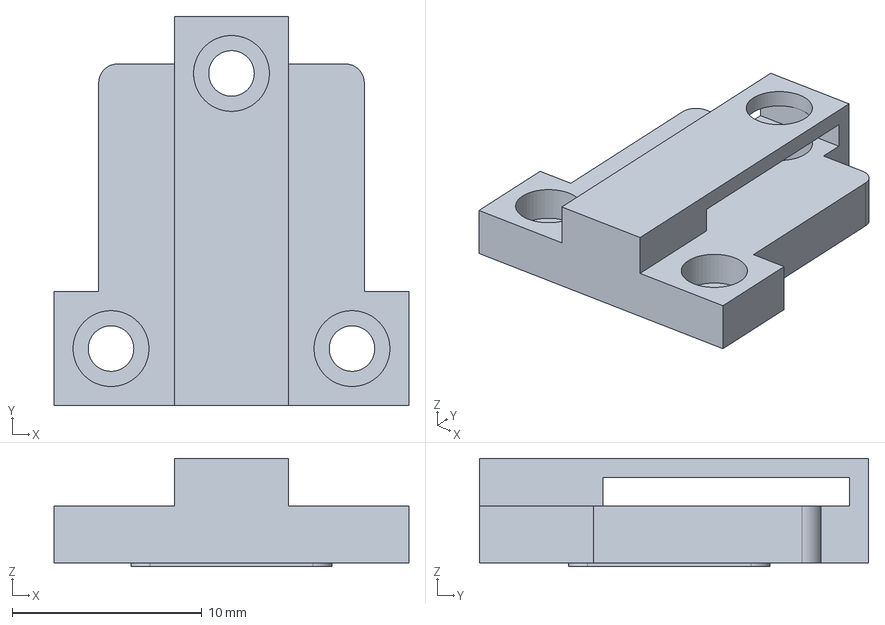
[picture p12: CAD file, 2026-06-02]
CAD/Band/Band.FCStd
18.7 x 20.5 x 5.70 mm

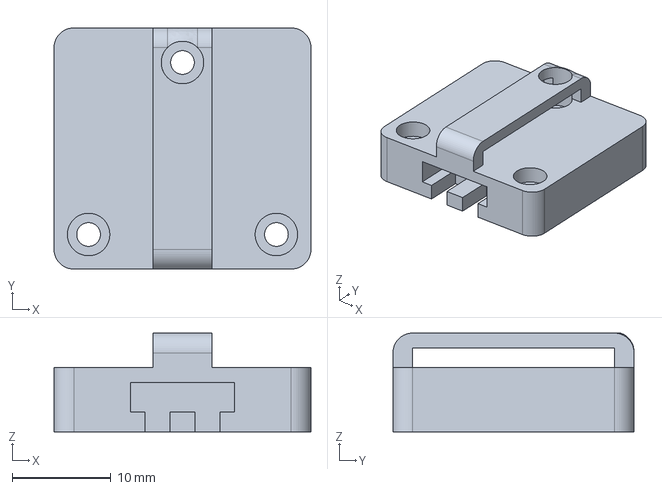
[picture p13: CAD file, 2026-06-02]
CAD/Band/LRA/LRA.FCStd
26.0 x 24.4 x 10.0 mm

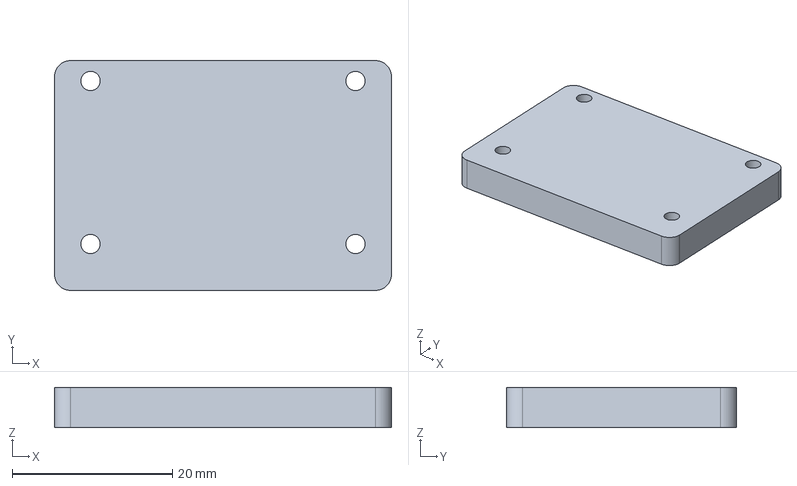
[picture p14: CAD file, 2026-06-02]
CAD/Pin/Pin.FCStd
42.0 x 28.6 x 5.00 mm

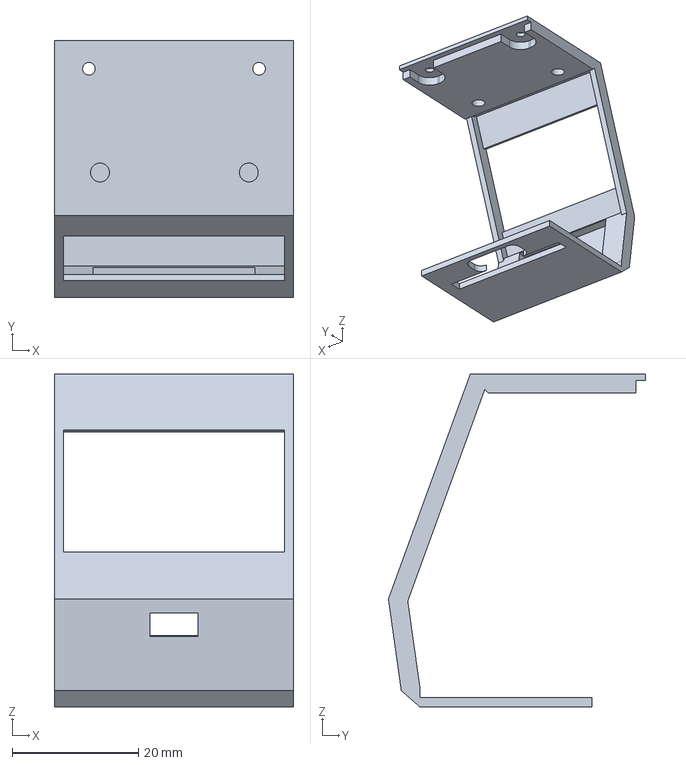
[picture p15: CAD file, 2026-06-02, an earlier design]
CAD/Pin/PinOld.FCStd
38.0 x 40.8 x 52.8 mm

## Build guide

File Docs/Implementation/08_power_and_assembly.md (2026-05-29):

# Power & Assembly — Wristband

How the wristband is wired in v4. Built around three commercial breakouts so
the whole supply path is socketable for bench work; the goal is no shared
rail between the radio and the LRAs (the v3 brownouts that drove the policy
caps came from exactly that mistake).

## Block diagram

```
       USB-C (host)              Single-cell Li-ion
            │                            │
            ▼                            ▼
 ┌──────────────────────────────────────────────┐
 │   BQ25185 charger board (USB aux + power-path)│
 │   LOAD = Vsys (≈ Vbat or VUSB-drop)           │
 └──────────────┬───────────────────┬───────────┘
                │                   │
                ▼                   ▼
   ┌────────────────────┐   ┌─────────────────────────┐
   │ 5 V boost converter│   │ 3.3 V buck converter    │
   │  → XIAO 5V pin     │   │  → mux + driver rail    │
   └────────┬───────────┘   └─────────────┬───────────┘
            │ 5 V                          │ 3.3 V (haptic rail)
            ▼                              │
 ┌──────────────────────────┐              │
 │   Seeed XIAO nRF52840    │              │
 │   (logic + BLE radio)    │              │
 └─────┬────────────────┬───┘              │
       │ I2C1            │ GND ── common ──┤
       │ SCL = D5 (P0.05)│                 │
       │ SDA = D4 (P0.04)│                 ▼
       │                 │      ┌──────────────────────┐
       │                 │      │  PCA9546A mux @ 0x70 │
       │                 │      │  (Qwiic 3.3 V power) │
       └─────────────────┴──────┤                      │
                                ├── ch0 → DA7280 + LRA (LEFT)
                                ├── ch1 → DA7280 + LRA (CENTER-LEFT)
                                ├── ch2 → DA7280 + LRA (CENTER-RIGHT)
                                └── ch3 → DA7280 + LRA (RIGHT)
```

The 5 V boost is needed because the XIAO BLE board's `VIN` (the 5V-labelled pad) expects 3.5–5.5 V; a single-cell Li-ion at 3.7 V works but droops under load. The 3.3 V buck is independent so the haptic rail can't sag the radio's supply (the v3 brownout failure mode).

## Boards & roles

| Block | Part | Role |
|---|---|---|
| MCU | Seeed XIAO nRF52840 (USB-powered) | BLE peripheral, I2C master |
| Charger  | BQ25185 breakout | Battery charging, power-path Vsys to LOAD |
| Buck | TPS62827 breakout (3.3 V output) | Dedicated 3.3 V rail for the haptic stack |
| Mux | PCA9546A breakout @ 0x70 (Qwiic) | 4-channel I2C switch, daisy-chains 3.3 V to driver boards |
| Driver | 4× SparkFun DA7280 + Jinlong G1040003D | One LRA per mux channel, all share I2C addr 0x4A |

## Wiring rules that matter

1. **Common ground.** XIAO GND **and** the buck output GND **and** the BQ25185
   ground **must** be tied together. I2C signals reference ground; the two
   halves of the system floating apart would NAK every transaction even
   though every chip is alive. This is the single most likely thing to
   forget on first assembly.

2. **No additional I2C pull-ups.** The Qwiic mux board carries its own 10 kΩ
   pull-ups, and each DA7280 board does too. With the four daisy-chained
   driver boards that totals 5 × 10 kΩ ≈ 2 kΩ on each line, which is healthy
   for a 400 kHz bus on a short cable run. Adding more would over-drive the
   bus and increase rise-time crosstalk.

3. **Power the haptic rail from the buck only.** Don't bridge the XIAO's
   3V3 output to the mux VCC even "as a backup." That re-creates the v3
   shared-rail problem the moment you also have USB plugged in.

4. **Mux comes up before the nRF probes I2C.** This is the natural order on
   plug-in: BQ25185 LOAD is stable in microseconds, the buck soft-starts in
   <1 ms, the nRF needs ~10 ms before driver init runs. No firmware delay
   needed. (See "Why we don't gate `EN` from the nRF" below.)

5. **`i2c-mux-idle-disconnect` is set in the overlay.** The in-tree TCA954X
   driver re-writes the channel mask before every transaction, which means
   the mux can never be left in a stale state and the PCA9546A `/RST` pin
   doesn't need to be wired. If you ever assemble a production rev that
   wants a hardware-recovery hammer, route `/RST` to a free nRF GPIO; it's
   not load-bearing today.

## Current budget

Worst case at the all-on-stress step (selftest T4, amp = 60 on all four
channels simultaneously):

| Source | Value |
|---|---|
| 4 × LRA peak current | ≈ 4 × 165 mA = 660 mA |
| 4 × DA7280 + mux quiescent | ≈ 30 mA |
| Buck conversion overhead | ≈ 50 mA equivalent at LOAD |
| **Sum at BQ25185 LOAD pin** | **≈ 740 mA** |
| BQ25185 LOAD rating | 1 A |

Comfortable, not luxurious. The TPS62827 (2.5–4 A capable) is over-sized;
the BQ25185 LOAD pin is the bottleneck. If a future hardware rev wants
headroom for additional actuators, swap to a higher-current power-path PMIC
before touching the buck.

## Boot order

1. USB plug-in → VBUS rises.
2. XIAO onboard regulator brings nRF up; ROM bootloader runs (~5 ms).
3. In parallel: BQ25185 routes Vsys to LOAD; TPS62827 soft-starts to 3.3 V
   (<1 ms after EN sees Vin); mux + four DA7280 boards are I2C-ready.
4. Zephyr early init runs; I2C controller is configured at the
   `I2C_INIT_PRIORITY` pass.
5. `ti,tca9546a` driver probes 0x70 (writes `0x00`, expects ACK) at
   `CONFIG_I2C_TCA954X_ROOT_INIT_PRIO=I2C_INIT_PRIORITY`.
6. `dlg,da7280` driver probes 0x4A on each child bus at
   `CONFIG_HAPTIC_DA7280_INIT_PRIORITY=80` (after the channel buses come up
   at `CONFIG_I2C_TCA954X_CHANNEL_INIT_PRIO=70`). `SAFE_INIT` writes
   `TOP_CTL2=0` and forces `OP_MODE=INACTIVE` before any config — this
   defangs the chip if it survived a host reset with non-zero amplitude.
7. `main()` runs `hapnav_haptics_init()` → if `CONFIG_HAPNAV_SELFTEST=y`
   the bench runner thread starts; otherwise the 20 Hz worker is scheduled.
8. `wrist_ble_init()` brings up the BLE peripheral and starts advertising
   as `HapNav-Wrist`.

## Why we don't gate `EN` from the nRF (yet)

The TPS62827's `EN` pin is left tied high so the buck is on whenever the
charger is providing Vsys. Wiring `EN` to a free nRF GPIO would let the
firmware cut the entire haptic subsystem (saves the buck's quiescent draw
and the four DA7280 standby currents during long idle stretches). The
trade-off is a startup dependency: the nRF would have to assert `EN`,
wait ~2 ms for the buck to settle, and only then init I2C — otherwise the
mux probe NAKs.

Worth doing for battery-life work later; not needed for the selftest or
for normal navigation. If you do wire it, give the GPIO a DT alias
(`hapnav-buck-en`), assert it at the very top of `hapnav_haptics_init()`
with a `k_msleep(2)` settle, and bump `CONFIG_I2C_TCA954X_ROOT_INIT_PRIO`
above the GPIO init priority.

## Verifying assembly before first power-up

Quick continuity / smoke checks before you plug USB:

1. Multimeter continuity from XIAO GND pad → BQ25185 GND → TPS62827 GND →
   PCA9546A GND. Single common-ground island.
2. Multimeter resistance from XIAO 3V3 to PCA9546A 3.3 V pin. Should be
   **open** (no continuity). If it reads ohms-level, you've bridged the
   nRF rail to the haptic rail — fix before powering.
3. Inspect SDA/SCL between XIAO D4/D5 and the mux SCL/SDA pins; verify
   not crossed.

Then plug USB, watch the UART log, and confirm:

- One `*** Booting Zephyr OS build ***` line (not multiple — that means
  brownout reboots).
- Four `DA7280 @0x4a initialized: LRA, 170 Hz …` lines.
- `haptics: SELFTEST mode (4/4 channels ready)`.
- T0 reports `rev=0xba` for all four channels (the chip's WHO_AM_I).

Anything short of 4/4 means a mux channel is mis-wired or a DA7280 board
isn't seated.

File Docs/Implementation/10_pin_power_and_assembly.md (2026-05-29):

# Power & Assembly — Chest Pin

How the chest pin is wired in v1. Same charger / boost-buck / I²C topology
as the wristband ([08_power_and_assembly.md](08_power_and_assembly.md)),
just with different downstream loads (sensors instead of LRAs).

## Block diagram

```
       USB-C (host)              Single-cell Li-ion
            │                            │
            ▼                            ▼
 ┌──────────────────────────────────────────────┐
 │   BQ25185 charger board (USB aux + power-path)│
 │   LOAD = Vsys (≈ Vbat or VUSB-drop)           │
 └──────────────┬───────────────────┬───────────┘
                │                   │
                ▼                   ▼
   ┌────────────────────┐   ┌─────────────────────────┐
   │ 5 V boost converter│   │ 3.3 V buck converter    │
   │  → XIAO 5V pin     │   │  → I²C bus rail         │
   └────────┬───────────┘   └─────────────┬───────────┘
            │ 5 V                          │ 3.3 V (sensor bus)
            ▼                              │
 ┌──────────────────────────┐              │
 │ Seeed XIAO ESP32-S3      │              │
 │ (BLE central, fusion)    │              │
 └─────┬────────────────┬───┘              │
       │ I2C0            │ GND ── common ──┤
       │ SDA = D2 (GPIO3)│                 │
       │ SCL = D3 (GPIO4)│                 ▼
       │                 │      ┌──────────────────────────┐
       │                 │      │  Qwiic chain on 3.3 V    │
       └─────────────────┴──────┤                          │
                                ├── LSM6DSO IMU      @ 0x6B │
                                ├── LIS2MDL mag      @ 0x1E │
                                ├── VL53L5CX ToF     @ 0x29 → 0x2A (shifted by app)
                                └── VL53L1X head ToF @ 0x29 (after VL53L5CX moves)
```

## Wiring rules that matter

1. **Common ground.** XIAO GND, BQ25185 GND, buck output GND, and boost
   output GND must all be tied. Same rule as the wristband, same failure
   mode if violated — I²C signals reference ground.

2. **Match the I²C rail voltage to the MCU's I/O VDD.** The ESP32-S3's
   I/O switches at its internal 3.3 V supply. The pull-ups on the Qwiic
   boards live on the **buck's** 3.3 V output. Both rails must measure
   close to 3.3 V — if the buck reads 3.0 V or 3.6 V, the bus pull-up
   reference is wrong relative to the MCU's input thresholds and you
   can get sustained NAKs on a bus that otherwise looks healthy.

3. **No additional I²C pull-ups.** Each SparkFun Qwiic board carries
   10 kΩ. With four daisy-chained boards (IMU, mag, VL53L5CX, VL53L1X)
   that's ~ 2.5 kΩ parallel — fine for 400 kHz.

4. **Boot sequence matters for the dual-VL53.** Both VL53L5CX and VL53L1X
   default to 7-bit `0x29`. The pin firmware holds the VL53L1X in `XSHUT`
   (D7 / GPIO1_12 = ESP32-S3 GPIO44 low) until after the VL53L5CX has
   been re-addressed to `0x2A` via the vendor ULD; only then does the
   deferred Zephyr driver release `XSHUT` and bring the VL53L1X up at
   `0x29`. See [09_head_clearance.md](09_head_clearance.md) for the
   full dance.

5. **Mounting holes on the BQ25185 are mechanical-only.** The screw holes
   on the SparkFun breakout are not connected to any signal or rail
   (worst case they tie to the chip's GND-thermal-pad). Tying an
   otherwise-unused ESP32-S3 GPIO to one for mechanical anchoring is
   safe — **except** if you use a strapping pin. Avoid:

   | XIAO pin | ESP32-S3 GPIO | Why |
   |---|---|---|
   | D2 | GPIO0_3 | strapping pin (configures JTAG vs. USB-Serial-JTAG); now in use as **I²C0 SDA** with the Qwiic pull-ups holding it high at reset |
   | D3 | GPIO0_4 | now in use as **I²C0 SCL** |
   | D7 | GPIO1_12 (= GPIO44) | now in use as **VL53L1X XSHUT** (default UART0 RX, but we use USB-Serial-JTAG for the console) |
   | — | GPIO0    | strapping pin (low = enter download mode at reset) — not on the XIAO header but exposed on some adapters |
   | — | GPIO45 / GPIO46 | flash-voltage / ROM-message strapping — not on the XIAO header |

   On the current pin revision D2/D3 carry the I²C bus and D7 is XSHUT,
   so D0, D1, D6, D8, D9, D10 are the remaining safe anchor candidates.

## Sensor positioning

The two ToF sensors do not share an axis with the chest pin's main face —
their angles are fixed by the enclosure geometry:

| Sensor | World-frame tilt | Relative to pin face |
|---|---|---|
| VL53L5CX (forward, 8×8 grid) | −8° (downward) | 0° (face flush) |
| VL53L1X (head clearance, 1-zone) | +20° (upward)  | +28° wedge above VL53L5CX face |

Derivations and the alternative tilts considered: see
[09_head_clearance.md](09_head_clearance.md).

## Current budget

The pin draws much less than the wristband — no LRAs, no high-current
spikes. At full activity (10 Hz ToF + 10 Hz IMU + 10 Hz BLE write):

| Source | Estimate |
|---|---|
| ESP32-S3 with BLE TX bursts | ~ 80–120 mA average, ~ 200 mA peaks |
| VL53L5CX continuous ranging | ~ 25 mA |
| VL53L1X continuous ranging  | ~ 15 mA |
| LSM6DSO + LIS2MDL idle | ~ 1 mA total |
| **Sum** | **≈ 150 mA** |

Well within the BQ25185's 1 A LOAD pin rating. The 5 V boost handles
the radio peaks; the 3.3 V buck handles the sensors.

## Verifying assembly before first power-up

The same multimeter checks as the wristband apply (continuity from XIAO
GND to all GNDs; resistance between XIAO 3V3 and the buck 3V3 should be
**open** — those are intentionally separate rails). Then plug USB and
watch the UART log:

```
*** Booting Zephyr OS build v4.4.0-XXX ***
[xx] <inf> hapnav_pin: HapNav pin: boot
[xx] <inf> hapnav_obstacle: Obstacle pipeline ready (tilt 8.0°, …)
[xx] <inf> pin_sensors: I²C scan on i2c@60013000:
[xx] <inf> pin_sensors:   found 0x1E (LIS2MDL magnetometer)
[xx] <inf> pin_sensors:   found 0x29 (VL53L5CX or VL53L1X — default)
[xx] <inf> pin_sensors:   found 0x6B (LSM6DSO IMU — SA0 high)
[xx] <inf> pin_sensors:   3 device(s) on the bus
```

That `3 device(s) on the bus` line is the single best confirmation that
the power topology is right and the bus is healthy. If it reads 0, the
bus is electrically dead — the diagnostic tree under "Hardware
diagnostics" in the pin's bring-up notes lists the checks in order.

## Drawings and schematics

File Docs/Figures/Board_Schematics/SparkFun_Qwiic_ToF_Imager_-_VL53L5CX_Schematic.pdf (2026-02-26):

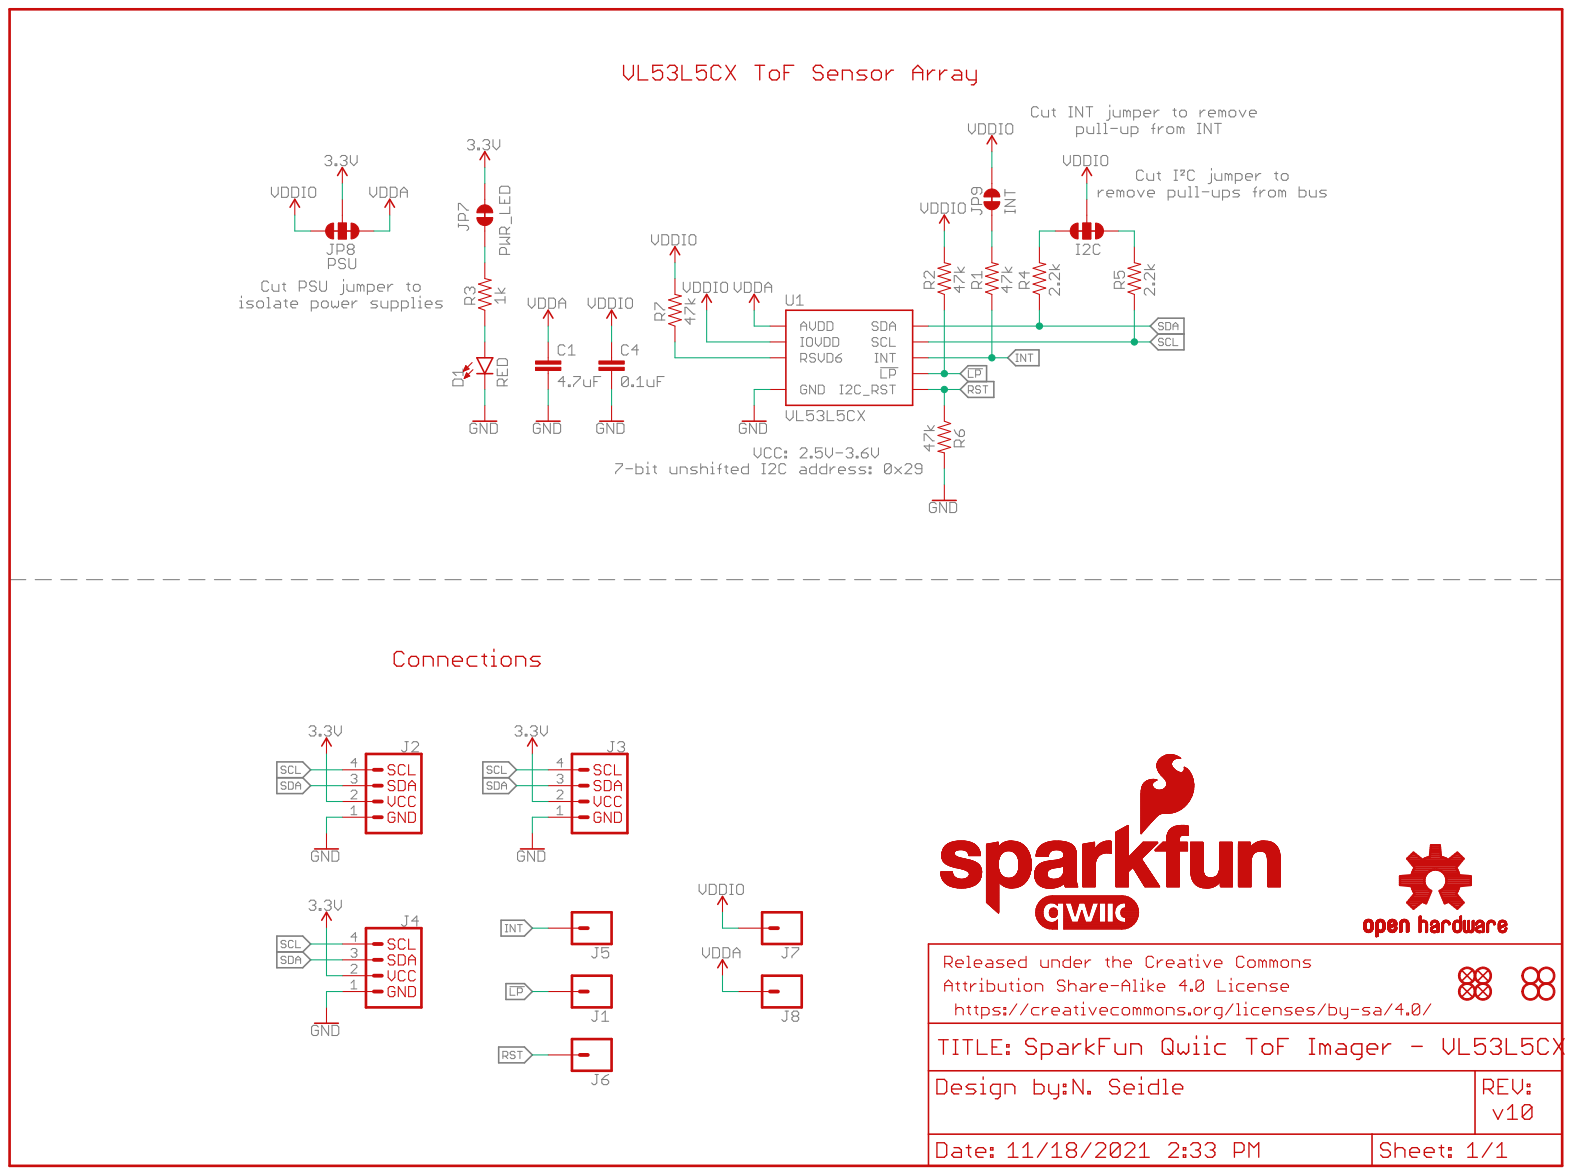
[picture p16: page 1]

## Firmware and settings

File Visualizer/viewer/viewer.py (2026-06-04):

#!/usr/bin/env python3
"""HapNav pin live visualizer.

Connects to the pin's USB-Serial-JTAG console (default `/dev/ttyACM1`,
matching the firmware's per-sample `PIN {...}` trace), parses the JSON
stream, and renders the three muxed ToFs + BNO055 IMU orientation in a
Viser scene.

Hierarchy / behaviour:
  /pin                anchored at config.PIN_WORLD_POSITION, wxyz = BNO055 quaternion
    /pin/imu          cosmetic BNO055 breakout
    /pin/tof_front    VL53L5CX 8×8 — point cloud + 64 zone rays
    /pin/tof_head     VL53L1X +20° — single ray + hit point
    /pin/tof_down     VL53L1X 45° — single ray + hit point
"""

import argparse
import logging
import time
from dataclasses import dataclass, field
from pathlib import Path

import numpy as np
import viser

from . import config
from .config import SensorKind
from .filters import TemporalFilter, fit_plane, fit_plane_ransac
from .geometry import (
    CoordinateMethod,
    compute_zone_angles,
    distances_to_points,
    get_colors,
)
from .logging_config import setup_logging
from .scene import (
    SceneHandles,
    ToFHandles,
    create_grid,
    create_scene_hierarchy,
    slug_path,
    update_grid_rays,
    update_single_zone_ray,
)
from .serial_reader import SerialReader

logger = logging.getLogger("hapnav_pin_viewer.main")


# Bit positions of the obstacle flag byte (mirrors firmware ble_proto.h).
FLAG_NAMES = [
    (0x01, "STATIONARY"),
    (0x02, "SENSOR_BLOCKED"),
    (0x04, "MOSTLY_INVALID"),
    (0x08, "YAW_SLEWING"),
    (0x10, "DROPOFF"),
    (0x20, "HEAD_OBSTACLE"),
]


def _quat_multiply(a: np.ndarray, b: np.ndarray) -> np.ndarray:
    """Hamilton-convention WXYZ quaternion product, a ⊗ b."""
    aw, ax, ay, az = a
    bw, bx, by, bz = b
    return np.array([
        aw * bw - ax * bx - ay * by - az * bz,
        aw * bx + ax * bw + ay * bz - az * by,
        aw * by - ax * bz + ay * bw + az * bx,
        aw * bz + ax * by - ay * bx + az * bw,
    ], dtype=np.float32)


@dataclass
class MappingState:
    """World-space accumulation for the front 8×8 grid only."""

    points: list[np.ndarray] = field(default_factory=list)
    colors: list[np.ndarray] = field(default_factory=list)
    _clear_requested: bool = False

    def request_clear(self):
        self._clear_requested = True

    def process_clear_if_requested(self) -> bool:
        if self._clear_requested:
            self._clear_requested = False
            self.points.clear()
            self.colors.clear()
            return True
        return False

    def add(self, pts: np.ndarray, cols: np.ndarray):
        self.points.append(pts)
        self.colors.append(cols)

    def get_display_data(self) -> tuple[np.ndarray, np.ndarray]:
        if not self.points:
            return np.empty((0, 3), dtype=np.float32), np.empty((0, 3), dtype=np.uint8)
        if len(self.points) == 1:
            return self.points[0], self.colors[0]
        return np.vstack(self.points), np.vstack(self.colors)

    def total_points(self) -> int:
        return sum(len(p) for p in self.points)

    def downsample(self, voxel_size: float, max_points: int):
        if not self.points:
            return
        all_pts = np.vstack(self.points)
        all_cols = np.vstack(self.colors)
        all_pts, all_cols = voxel_downsample(all_pts, all_cols, voxel_size)
        if len(all_pts) > max_points:
            all_pts = all_pts[-max_points:]
            all_cols = all_cols[-max_points:]
        self.points = [all_pts]
        self.colors = [all_cols]


def voxel_downsample(points: np.ndarray, colors: np.ndarray, voxel_size: float):
    if len(points) == 0:
        return points, colors
    vi = np.ascontiguousarray(np.floor(points / voxel_size).astype(np.int64))
    keys = vi.view(dtype=[("x", np.int64), ("y", np.int64), ("z", np.int64)]).ravel()
    _, unique_idx = np.unique(keys, return_index=True)
    return points[unique_idx], colors[unique_idx]


class HapNavViewer:
    """Live viewer for one HapNav pin instance."""

    def __init__(self, port: str, baud: int = 115200):
        self.serial_reader = SerialReader(port, baud)
        self.zone_angles = compute_zone_angles()
        self.temporal_filter = TemporalFilter()

    # ── setup ───────────────────────────────────────────────────────────

    def _setup_scene(self, server: viser.ViserServer):
        create_grid(server)
        assets_dir = Path(__file__).parent.parent / "assets"
        self.scene: SceneHandles = create_scene_hierarchy(
            server, assets_dir, self.zone_angles
        )

    def _setup_gui(self, server: viser.ViserServer, mapping_state: MappingState):
        with server.gui.add_folder("Pin status"):
            self.fps_text = server.gui.add_text("Frames/s", initial_value="0")
            self.imu_text = server.gui.add_text("IMU", initial_value="Not connected")
            self.front_text = server.gui.add_text("Front 8×8", initial_value="Waiting…")
            self.head_text = server.gui.add_text("Head ToF (mm)", initial_value="—")
            self.down_text = server.gui.add_text("Down ToF (mm)", initial_value="—")
            self.urgency_text = server.gui.add_text("Urgency [L CL CR R]", initial_value="0 0 0 0")
            self.flags_text = server.gui.add_text("Obstacle flags", initial_value="—")

        with server.gui.add_folder("Display"):
            self.point_size = server.gui.add_slider(
                "Point Size", min=0.001, max=0.020, step=0.001, initial_value=0.005
            )
            self.show_rays = server.gui.add_checkbox("Show Zone Rays", initial_value=True)
            self.clip_rays = server.gui.add_checkbox("Clip to Measurement", initial_value=False)

            @self.show_rays.on_update
            def _(_event):
                self.clip_rays.disabled = not self.show_rays.value

            server.gui.add_markdown("---")
            self.coord_method = server.gui.add_dropdown(
                "Front grid method",
                options=[m.value for m in CoordinateMethod],
                initial_value=CoordinateMethod.UNIFORM.value,
            )

            server.gui.add_markdown("---")
            self.apply_imu = server.gui.add_checkbox(
                "Apply IMU Rotation", initial_value=True
            )
            server.gui.add_markdown("---")
            self.filter_on = server.gui.add_checkbox("Front grid filtering", initial_value=False)
            self.filter_strength = server.gui.add_slider(
                "Filter Strength", min=0.0, max=1.0, step=0.05,
                initial_value=0.5, disabled=True,
            )

            @self.filter_on.on_update
            def _(_event):
                self.filter_strength.disabled = not self.filter_on.value
                if not self.filter_on.value:
                    self.temporal_filter.reset()

            server.gui.add_markdown("---")
            self.fit_plane_on = server.gui.add_checkbox("Fit Plane (front)", initial_value=False)
            self.plane_method = server.gui.add_dropdown(
                "Plane method",
                options=["Least Squares", "RANSAC"],
                initial_value="Least Squares",
                disabled=True,
            )
            self.ransac_thr = server.gui.add_slider(
                "RANSAC Threshold (mm)", min=1, max=50, step=1,
                initial_value=10, visible=False,
            )
            self.plane_rmse = server.gui.add_text("Plane RMSE (mm)", initial_value="—")

            @self.fit_plane_on.on_update
            def _(_event):
                self.plane_method.disabled = not self.fit_plane_on.value
                self.ransac_thr.visible = (
                    self.fit_plane_on.value
                    and self.plane_method.value == "RANSAC"
                )
                if not self.fit_plane_on.value:
                    self.plane_rmse.value = "—"

            @self.plane_method.on_update
            def _(_event):
                self.ransac_thr.visible = self.plane_method.value == "RANSAC"

        with server.gui.add_folder("Mapping (front grid)"):
            self.mapping_on = server.gui.add_checkbox("Mapping Mode", initial_value=False)
            self.voxel = server.gui.add_slider(
                "Voxel Size (mm)", min=5, max=50, step=5, initial_value=10
            )
            self.max_pts = server.gui.add_slider(
                "Max Points (k)", min=10, max=500, step=10, initial_value=100
            )
            self.point_count = server.gui.add_text("Points", initial_value="0")
            clear_btn = server.gui.add_button("Clear Map")

            @clear_btn.on_click
            def _(_event):
                mapping_state.request_clear()

    # ── per-frame ───────────────────────────────────────────────────────

    def _apply_pin_rotation(self, quaternion: np.ndarray, imu_connected: bool):
        """Set /pin's wxyz to the BNO055 quaternion, after applying the
        configurable world-frame correction (`IMU_QUAT_CORRECTION_WXYZ`).

        The firmware's axis remap aligns the BNO055 output with our pin
        body frame, but the BNO055's gravity+magnetic-north world frame may
        still differ from the viewer's world frame by a fixed rotation —
        that's what the correction quat compensates for. Defaults to
        identity; tune in `config.py` if the rendered pin doesn't track its
        physical orientation.
        """
        if self.apply_imu.value and imu_connected:
            corrected = _quat_multiply(
                np.asarray(config.IMU_QUAT_CORRECTION_WXYZ, dtype=np.float32),
                quaternion,
            )
            self.scene.pin.wxyz = tuple(float(x) for x in corrected)
        else:
            self.scene.pin.wxyz = (1.0, 0.0, 0.0, 0.0)

    def _update_front_grid(
        self,
        server: viser.ViserServer,
        tof: ToFHandles,
        distances: np.ndarray,
        status: np.ndarray,
        front_seen: bool,
        mapping_state: MappingState,
        plane_handle,
    ):
        """Update the front 8×8 grid: point cloud, mapping accumulation,
        plane fit, and per-zone ray clipping."""
        if not front_seen:
            self.front_text.value = "Waiting…"
            return plane_handle

        if self.filter_on.value:
            distances = self.temporal_filter.apply(
                distances, self.filter_strength.value
            )

        method = next(
            m for m in CoordinateMethod if m.value == self.coord_method.value
        )

        # The pin's firmware emits raw VL53L5CX status codes (5 = valid).
        valid_mask = (status == 5) & (distances >= config.MIN_RANGE_MM)
        points_local = distances_to_points(distances, self.zone_angles, method)
        colors = get_colors(distances, status)

        if not np.any(valid_mask):
            self.front_text.value = "No valid pixels"
            return plane_handle

        valid_local = points_local[valid_mask].astype(np.float32)
        valid_colors = colors[valid_mask]

        if self.mapping_on.value:
            # Accumulate in pin-local space; viser's parent transform will
            # carry the IMU rotation onto the rendered points.
            mapping_state.add(valid_local, valid_colors)
            if (
                mapping_state.total_points() > config.DOWNSAMPLE_POINT_THRESHOLD
                or len(mapping_state.points) > config.DOWNSAMPLE_BUFFER_THRESHOLD
            ):
                mapping_state.downsample(self.voxel.value / 1000.0, self.max_pts.value * 1000)
            display_points, display_colors = mapping_state.get_display_data()
            self.point_count.value = f"{len(display_points):,}"
            server.scene.add_point_cloud(
                tof.point_path,
                points=display_points,
                colors=display_colors,
                point_size=self.point_size.value,
                point_shape="circle",
            )
        else:
            server.scene.add_point_cloud(
                tof.point_path,
                points=valid_local,
                colors=valid_colors,
                point_size=self.point_size.value,
                point_shape="circle",
            )

        # Plane fit on the live front-grid points (sensor-local frame).
        if self.fit_plane_on.value and len(valid_local) >= 3:
            if self.plane_method.value == "RANSAC":
                plane_fit = fit_plane_ransac(
                    valid_local, threshold=self.ransac_thr.value / 1000.0
                )
            else:
                plane_fit = fit_plane(valid_local)
            if plane_fit is not None:
                pos, wxyz, size, rmse_mm = plane_fit
                self.plane_rmse.value = f"{rmse_mm:.2f}"
                plane_path = f"/pin/{slug_path(tof.mount.name)}/sensor/plane"
                plane_handle = server.scene.add_box(
                    plane_path,
                    dimensions=(size, size, 0.0001),
                    position=pos,
                    wxyz=wxyz,
                    color=(255, 255, 0),
                    opacity=0.5,
                )

        valid_distances = distances[valid_mask]
        self.front_text.value = (
            f"{int(valid_distances.min())}–{int(valid_distances.max())} mm "
            f"({int(valid_mask.sum())}/{config.NUM_ZONES} valid)"
        )

        # Per-zone ray update.
        if self.show_rays.value:
            update_grid_rays(
                server, tof, self.zone_angles,
                visible=True,
                distances_mm=distances if self.clip_rays.value else None,
            )
        else:
            for r in tof.rays:
                r.visible = False

        return plane_handle

    def _update_single_zone(
        self,
        server: viser.ViserServer,
        tof: ToFHandles,
        distance_mm: float,
        gui_text,
    ):
        """Update a head/down ToF: ray length + single hit point."""
        # GUI label.
        gui_text.value = "—" if distance_mm < 0 else f"{int(distance_mm)}"

        # Ray.
        update_single_zone_ray(
            server, tof,
            visible=self.show_rays.value,
            distance_mm=distance_mm,
        )

        # Single hit point in sensor-local coordinates.
        if distance_mm >= config.SINGLE_ZONE_MIN_MM:
            pt_z = min(distance_mm / 1000.0, config.SINGLE_ZONE_MAX_MM / 1000.0)
            color = tof.mount.fallback_color[:3] if tof.mount.fallback_color else (255, 255, 0)
            server.scene.add_point_cloud(
                tof.point_path,
                points=np.array([[0.0, 0.0, pt_z]], dtype=np.float32),
                colors=np.array([color], dtype=np.uint8),
                point_size=max(self.point_size.value * 2.0, 0.006),
                point_shape="circle",
            )
        else:
            server.scene.remove_by_name(tof.point_path)

    def _update_overlay(self, urgency: np.ndarray, nearest_mm: int, flags: int):
        self.urgency_text.value = " ".join(str(int(v)) for v in urgency)
        active_flags = [name for bit, name in FLAG_NAMES if flags & bit]
        if not active_flags:
            label = f"0x{flags:02x}"
        else:
            label = f"0x{flags:02x}  " + " | ".join(active_flags)
        if nearest_mm >= 0:
            label += f"   near={nearest_mm} mm"
        self.flags_text.value = label

    def _process_frame(
        self,
        server: viser.ViserServer,
        mapping_state: MappingState,
        plane_handle,
    ):
        frame = self.serial_reader.get_frame()

        # Status panel.
        self.fps_text.value = f"{self.serial_reader.data_fps:.1f}"
        self.imu_text.value = "Connected" if frame["imu_connected"] else "Not connected"

        # Pin orientation.
        self._apply_pin_rotation(frame["quaternion"], frame["imu_connected"])

        # Mapping-mode clear handling (must run before adding new points).
        if mapping_state.process_clear_if_requested():
            self.point_count.value = "0"
            # Remove every front-grid mapping point cloud explicitly.
            for tof in self.scene.tofs:
                if tof.mount.kind is SensorKind.GRID_8X8:
                    server.scene.remove_by_name(tof.point_path)

        # Per-ToF updates. Mount identity (config.TOF_*) drives which gauge
        # / GUI label gets the reading.
        for tof in self.scene.tofs:
            if tof.mount is config.TOF_FRONT:
                plane_handle = self._update_front_grid(
                    server, tof,
                    frame["front_distances"], frame["front_status"],
                    frame["front_seen"],
                    mapping_state, plane_handle,
                )
            elif tof.mount is config.TOF_HEAD:
                self._update_single_zone(
                    server, tof, frame["head_distance_mm"], self.head_text
                )
            elif tof.mount is config.TOF_DOWN:
                self._update_single_zone(
                    server, tof, frame["down_distance_mm"], self.down_text
                )

        # Obstacle overlay.
        self._update_overlay(frame["urgency"], frame["nearest_mm"], frame["flags"])

        if plane_handle is not None:
            plane_handle.visible = self.fit_plane_on.value

        return plane_handle

    # ── main loop ───────────────────────────────────────────────────────

    def run(self, host: str = "0.0.0.0", port: int = 8080):
        self.serial_reader.connect()
        self.serial_reader.start()

        server = viser.ViserServer(host=host, port=port)
        logger.info("Viser server at http://localhost:%d", port)

        @server.on_client_connect
        def _on_client_connect(client: viser.ClientHandle):
            client.camera.position = (0.6, -0.6, 0.5)
            client.camera.look_at = config.PIN_WORLD_POSITION
            client.camera.up = (0.0, 0.0, 1.0)
            client.camera.near = 0.001
            client.camera.fov = 0.55

        mapping_state = MappingState()
        self._setup_scene(server)
        self._setup_gui(server, mapping_state)

        plane_handle = None
        try:
            while True:
                t0 = time.time()
                plane_handle = self._process_frame(server, mapping_state, plane_handle)
                dt = time.time() - t0
                if dt < config.FRAME_TIME:
                    time.sleep(config.FRAME_TIME - dt)
        except KeyboardInterrupt:
            logger.info("Shutting down…")
        finally:
            self.serial_reader.stop()


def main():
    parser = argparse.ArgumentParser(description="HapNav pin live visualizer")
    parser.add_argument(
        "--port", "-p",
        default="/dev/ttyACM1",
        help="Serial port the pin is on (default: /dev/ttyACM1)",
    )
    parser.add_argument(
        "--baud", "-b", type=int, default=115200, help="Baud rate (default: 115200)"
    )
    parser.add_argument(
        "--host", default="0.0.0.0", help="Viser server host (default: 0.0.0.0)"
    )
    parser.add_argument(
        "--viser-port", type=int, default=8080,
        help="Viser server port (default: 8080)"
    )
    parser.add_argument(
        "--debug", "-d", action="store_true", help="Enable debug logging"
    )
    args = parser.parse_args()

    setup_logging(level=logging.DEBUG if args.debug else logging.INFO)

    viewer = HapNavViewer(port=args.port, baud=args.baud)
    viewer.run(host=args.host, port=args.viser_port)


if __name__ == "__main__":
    main()

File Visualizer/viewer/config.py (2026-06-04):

"""HapNav pin sensor configuration.

The original viewer was built around a breadboard carrying a single VL53L5CX
and a separate BNO08x IMU. The pin is laid out differently: an integrated
BNO055 (whose firmware does the body-frame axis remap so the quaternion it
emits is already pin body → world) plus three ToFs muxed on one I²C bus —

  * FRONT  VL53L5CX  (8×8 grid)  — optical axis aligned with pin "forward"
                                   plus 8°  downtilt
  * HEAD   VL53L1X   (single)    — optical axis aligned with pin "forward"
                                   plus 20° uptilt
  * DOWN   VL53L1X   (single)    — optical axis aligned with pin "forward"
                                   plus 45° downtilt

All three ToFs render with the VL53L5CX board texture for now (a placeholder
until the proper assets/configs for the single-zone breakouts land).

Pin body frame (matches the firmware's `obstacle.c`):
  +X right, +Y back, +Z up — so "forward" is **-Y**.
"""

from dataclasses import dataclass
from enum import Enum

import numpy as np


# ────────────────────────────────────────────────────────────────────────────
# Front VL53L5CX specs (drives the 8×8 grid pipeline).
# ────────────────────────────────────────────────────────────────────────────

RESOLUTION = 8                 # 8×8 zones
NUM_ZONES = 64
FOV_DIAGONAL_DEG = 65.0        # diagonal FoV; per-axis is FoV/√2 ≈ 45.96°

# Range gate for the front grid. The firmware uses 50–2000 mm in bench mode
# (`obstacle.c:42`); we follow that here so the colour ramp and the ray cull
# share the same bounds.
MIN_RANGE_MM = 50
MAX_RANGE_MM = 2000

# VL53L1X (head + down) usable distance gate, in mm.
SINGLE_ZONE_MIN_MM = 40
SINGLE_ZONE_MAX_MM = 4000

# Visualization frame rate.
TARGET_FPS = 30
FRAME_TIME = 1.0 / TARGET_FPS

# Mapping mode thresholds (front grid only; see viewer.py).
DOWNSAMPLE_POINT_THRESHOLD = 500
DOWNSAMPLE_BUFFER_THRESHOLD = 15


# ────────────────────────────────────────────────────────────────────────────
# Sensor mount config.
# ────────────────────────────────────────────────────────────────────────────

class SensorKind(Enum):
    """How many rays a ToF emits and therefore how it's rendered."""

    GRID_8X8 = "grid_8x8"
    SINGLE_ZONE = "single_zone"


@dataclass
class ToFMount:
    """Where one ToF sits on the pin and how it's oriented.

    `pin_position` is the location of the sensor's optical centre in pin-body
    coordinates (meters).

    `pin_orientation_wxyz` rotates the sensor's local frame
    (+X right, +Y up, +Z forward = optical axis) into the pin body frame
    (+X right, +Y back, +Z up). For "forward + tilt-down θ" the canonical
    rotation is R_x(90° + θ): the first 90° around X takes sensor +Z onto
    pin -Y (= forward), and the extra θ tilts the optical axis from -Y
    toward -Z. Negative θ for uptilt.

    `sensor_offset` is the chip-aperture offset relative to the board mesh
    centre — used to place the mesh around the sensor's optical centre so
    the textured breakout looks attached to the rays, not floating.
    """

    name: str
    pin_position: tuple[float, float, float]
    pin_orientation_wxyz: tuple[float, float, float, float]
    sensor_offset: tuple[float, float, float]
    dimensions: tuple[float, float, float]
    texture: str
    kind: SensorKind
    is_atlas: bool = True
    fallback_color: tuple[int, int, int, int] = (0, 100, 0, 255)


@dataclass
class IMUMount:
    """Position of the BNO055 chip inside the pin. Purely cosmetic — the
    quaternion still drives the *whole* pin frame's rotation, not just this
    breakout. The board mesh just helps the viewer "look" like a pin."""

    name: str
    pin_position: tuple[float, float, float]
    pin_orientation_wxyz: tuple[float, float, float, float]
    sensor_offset: tuple[float, float, float]
    dimensions: tuple[float, float, float]
    texture: str
    is_atlas: bool = True
    fallback_color: tuple[int, int, int, int] = (128, 0, 128, 255)


def _x_axis_quat_deg(angle_deg: float) -> tuple[float, float, float, float]:
    """Helper: WXYZ quaternion for a rotation around the pin's +X axis."""
    a = np.deg2rad(angle_deg) / 2.0
    return (float(np.cos(a)), float(np.sin(a)), 0.0, 0.0)


# Pin anchor in the world frame. With the BENCH_MODE pin at ~17 cm above the
# desk, Z = 0.17 puts the world "floor" plane at z=0 and the pin at a
# realistic perch above it. Tune freely; rays/points are children of the pin.
PIN_WORLD_POSITION = (0.0, 0.0, 0.17)


# All three ToF breakouts re-use the VL53L5CX texture for now — when proper
# VL53L1X assets land, swap the `texture` field per mount.
_VL53L5CX_TEXTURE = "vl53l5cx-atlas.png"
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

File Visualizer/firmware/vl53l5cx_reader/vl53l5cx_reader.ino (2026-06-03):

/*
 * VL53L5CX ToF Sensor + LSM6DSO IMU Reader for ESP32
 *
 * Reads 8x8 distance data from VL53L5CX and orientation from LSM6DSO,
 * outputs JSON over serial.
 */

#include <Wire.h>
#include <SparkFun_VL53L5CX_Library.h>
#include "SparkFunLSM6DSO.h"

#define VERSION "r.1.0"

#define SDA_PIN 21
#define SCL_PIN 22
#define I2C_SPEED 400000

// VL53L5CX ToF sensor
SparkFun_VL53L5CX sensor;
VL53L5CX_ResultsData measurementData;

// LSM6DSO IMU
LSM6DSO imu;
bool imuAvailable = false;

// Quaternion in w, x, y, z format
float quatW = 1.0f;
float quatX = 0.0f;
float quatY = 0.0f;
float quatZ = 0.0f;

// Mahony-style filter parameters
float twoKp = 2.0f * 0.8f;
float twoKi = 2.0f * 0.0f;

float integralFBx = 0.0f;
float integralFBy = 0.0f;
float integralFBz = 0.0f;

unsigned long lastImuMicros = 0;

void updateIMUFilter(float gx, float gy, float gz, float ax, float ay, float az, float dt) {
  // gx, gy, gz must be in rad/s
  // ax, ay, az can be in g or m/s^2, because we normalize them

  float recipNorm;
  float halfvx, halfvy, halfvz;
  float halfex, halfey, halfez;
  float qa, qb, qc;

  // Ignore invalid accelerometer data
  if ((ax == 0.0f) && (ay == 0.0f) && (az == 0.0f)) {
    return;
  }

  // Normalize accelerometer
  recipNorm = 1.0f / sqrt(ax * ax + ay * ay + az * az);
  ax *= recipNorm;
  ay *= recipNorm;
  az *= recipNorm;

  // Estimated direction of gravity
  halfvx = quatX * quatZ - quatW * quatY;
  halfvy = quatW * quatX + quatY * quatZ;
  halfvz = quatW * quatW - 0.5f + quatZ * quatZ;

  // Error is cross product between estimated and measured gravity
  halfex = (ay * halfvz - az * halfvy);
  halfey = (az * halfvx - ax * halfvz);
  halfez = (ax * halfvy - ay * halfvx);

  // Integral feedback
  if (twoKi > 0.0f) {
    integralFBx += twoKi * halfex * dt;
    integralFBy += twoKi * halfey * dt;
    integralFBz += twoKi * halfez * dt;

    gx += integralFBx;
    gy += integralFBy;
    gz += integralFBz;
  } else {
    integralFBx = 0.0f;
    integralFBy = 0.0f;
    integralFBz = 0.0f;
  }

  // Proportional feedback
  gx += twoKp * halfex;
  gy += twoKp * halfey;
  gz += twoKp * halfez;

  // Integrate quaternion rate
  gx *= (0.5f * dt);
  gy *= (0.5f * dt);
  gz *= (0.5f * dt);

  qa = quatW;
  qb = quatX;
  qc = quatY;

  quatW += (-qb * gx - qc * gy - quatZ * gz);
  quatX += (qa * gx + qc * gz - quatZ * gy);
  quatY += (qa * gy - qb * gz + quatZ * gx);
  quatZ += (qa * gz + qb * gy - qc * gx);

  // Normalize quaternion
  recipNorm = 1.0f / sqrt(quatW * quatW + quatX * quatX + quatY * quatY + quatZ * quatZ);
  quatW *= recipNorm;
  quatX *= recipNorm;
  quatY *= recipNorm;
  quatZ *= recipNorm;
}

void setup() {
  delay(2000);

  Serial.begin(115200);
  delay(1000);

  Serial.println("start");
  Serial.println("{\"status\":\"initializing\"}");

  Wire.begin(SDA_PIN, SCL_PIN);
  Wire.setClock(I2C_SPEED);

  Serial.println("{\"status\":\"i2c_ready\"}");

  // Initialize VL53L5CX
  if (!sensor.begin()) {
    Serial.println("{\"error\":\"tof_sensor_init_failed\"}");
    while (1) {
      delay(1000);
    }
  }

  Serial.println("{\"status\":\"tof_sensor_found\"}");

  sensor.setResolution(64);
  sensor.setRangingFrequency(15);
  sensor.startRanging();

  Serial.println("{\"status\":\"ranging_started\",\"resolution\":\"8x8\",\"frequency_hz\":15}");

  // Initialize LSM6DSO
  if (imu.begin()) {
    imuAvailable = true;
    Serial.println("{\"status\":\"imu_found\"}");
  } else {
    Serial.println("{\"status\":\"imu_not_found\"}");
  }

  if (imuAvailable) {
    if (imu.initialize(BASIC_SETTINGS)) {
      Serial.println("{\"status\":\"imu_settings_loaded\"}");
    } else {
      Serial.println("{\"status\":\"imu_settings_failed\"}");
    }

    lastImuMicros = micros();
    Serial.println("{\"status\":\"imu_ready\",\"mode\":\"lsm6dso_6axis_fusion\"}");
  }
}

void loop() {
  // Update IMU quaternion
  if (imuAvailable) {
    float ax = imu.readFloatAccelX();
    float ay = imu.readFloatAccelY();
    float az = imu.readFloatAccelZ();

    float gx = imu.readFloatGyroX();
    float gy = imu.readFloatGyroY();
    float gz = imu.readFloatGyroZ();

    // SparkFun LSM6DSO gyro is usually in deg/s.
    // Convert deg/s to rad/s for the filter.
    gx *= 0.01745329252f;
    gy *= 0.01745329252f;
    gz *= 0.01745329252f;

    unsigned long now = micros();
    float dt = (now - lastImuMicros) * 1e-6f;
    lastImuMicros = now;

    if (dt > 0.0f && dt < 0.1f) {
      updateIMUFilter(gx, gy, gz, ax, ay, az, dt);
    }
  }

  // Output ToF + quaternion JSON
  if (sensor.isDataReady()) {
    if (sensor.getRangingData(&measurementData)) {
      Serial.print("{\"distances\":[");

      for (int i = 0; i < 64; i++) {
        Serial.print(measurementData.distance_mm[i]);
        if (i < 63) Serial.print(",");
      }

      Serial.print("],\"status\":[");

      for (int i = 0; i < 64; i++) {
        Serial.print(measurementData.target_status[i]);
        if (i < 63) Serial.print(",");
      }

      Serial.print("],\"quat\":[");
      Serial.print(quatW, 6); Serial.print(",");
      Serial.print(quatX, 6); Serial.print(",");
      Serial.print(quatY, 6); Serial.print(",");
      Serial.print(quatZ, 6);

      Serial.print("],\"v\":\"");
      Serial.print(VERSION);
      Serial.println("\"}");
    }
  }

  delay(1);
}

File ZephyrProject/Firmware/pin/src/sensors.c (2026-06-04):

#include "sensors.h"

#include <hapnav/bno055.h>
#include <hapnav/vl53l5cx.h>
#include <hapnav/obstacle.h>
#include <hapnav/dropoff.h>

#include <zephyr/kernel.h>
#include <zephyr/device.h>
#include <zephyr/devicetree.h>
#include <zephyr/drivers/i2c.h>
#include <zephyr/drivers/sensor.h>
#include <zephyr/logging/log.h>
#include <zephyr/sys/printk.h>
#include <math.h>
#include <string.h>

LOG_MODULE_REGISTER(pin_sensors, LOG_LEVEL_INF);

/*
 * Pin sensor bring-up (v3 — everything on the mux):
 *   TCA9548A mux on i2c0 with four populated branches:
 *     ch0 (alias hapnav-tof-head)      → VL53L1X head (Zephyr sensor)
 *     ch1 (alias hapnav-tof-front-bus) → VL53L5CX via vendor ULD
 *     ch2 (alias hapnav-tof-down)      → VL53L1X down (Zephyr sensor)
 *     ch3 (alias hapnav-imu-bus)       → BNO055 9-DOF IMU @ 0x28 (NDOF fusion)
 *
 * Each ToF lives at its default 0x29 on its own muxed bus — no XSHUT, no
 * runtime address shift, no warm-reset retained-address handling. The BNO055
 * sits on its own muxed bus too, isolated from the ToFs except when ch3 is
 * routed. The Zephyr i2c-mux driver picks the channel transparently per
 * transfer.
 */

#define SAMPLE_PERIOD_MS  12            /* ~83 Hz (4× the previous 20 Hz cadence) */
#define SAMPLE_DT_S       (SAMPLE_PERIOD_MS / 1000.0f)

/* How often each of head + down VL53L1X actually gets sampled, in loop
 * counts. Head and down are 180° out of phase, so at the steady-state
 * effective ~50 Hz loop rate this puts each VL53L1X at ~6 Hz — well above
 * what slow-changing head-clearance / dropoff needs. Lower this for
 * snappier VL53L1X latency at the cost of lower main-loop rate. */
#define VL53L1X_SAMPLE_PERIOD_LOOPS  8

/* Head-clearance trigger envelope. Worn-pose default catches doorframes at
 * 1.0–2.5 m forward; bench mode shrinks it to a 15 cm slant. */
#if defined(CONFIG_HAPNAV_BENCH_MODE)
#define HEAD_PROXIMITY_MAX_MM       150
#else
#define HEAD_PROXIMITY_MAX_MM       2200
#endif
#define HEAD_PROXIMITY_MIN_MM        40   /* below this the reading is suspect */

/* DT handles */
#define TOF_FRONT_BUS_NODE   DT_ALIAS(hapnav_tof_front_bus)
#define TOF_HEAD_NODE        DT_ALIAS(hapnav_tof_head)
#define TOF_DOWN_NODE        DT_ALIAS(hapnav_tof_down)
#define IMU_BUS_NODE         DT_ALIAS(hapnav_imu_bus)

#define BNO055_I2C_ADDR      0x28   /* Adafruit BFF default (COM3=GND) */
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

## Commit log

2026-02-26 Add PRD diagrams and ToF schematic pdf
2026-03-03 Add chest pin render
2026-03-03 STMicroelectronics Driver
2026-03-03 Start Implement FIFO for IMU_Magnetometer
2026-04-14 docs: add schematics and sensor specs
2026-04-29 Add Object Detection Pipeline for ToF Sensor
    Implement object detection pipeline for VL53L5CX sensor with IMU compensation, including filtering, ground plane estimation, region growing, tracking, and haptic feedback.
2026-04-29 ToF and IMU(without magnetometer data) visualization
2026-05-06 Add docs, vibration motor driver and control logic (WIP)
    [da7280.c, main.c]
2026-05-29 feat: add bench mode, rework detection and render algorithms, add loggers, docs and misc
    [Band-BandMidplate.stl, Band-EnclosureBottomShell.stl, Band-EnclosureTopLid.stl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]
2026-06-02 Update algorithm to use three ToFs and CAD design updates
    [Band.FCStd, LRA.FCStd, Pin-HousingBackplate.stl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]
2026-06-02 Remove old stl(s)
    [Band-LRAHousing.stl, Band-LRAPlate.stl]
2026-06-02 Add mounting plate and remove stl(s)
    [Band-BandMidplate.stl, Band-EnclosureBottomShell.stl, Band-EnclosureTopLid.stl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]
2026-06-04 feat: rework visualization, add BNO055 board asset
    [config.py, scene.py, serial_reader.py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]
2026-06-04 fix: try and fix imu position in viser
    [config.py, viewer.py]
